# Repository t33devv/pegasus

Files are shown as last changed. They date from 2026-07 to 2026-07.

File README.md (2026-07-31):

# Pegasus
Quadruped Robot Dog

Fusion360 CAD


Pegasus has 4 legs, each a parallel five-bar linkage driven by two servos, plus a roll servo per leg (12 servos total). Controlled by a **Pimoroni Servo 2040** (RP2040) running **Pimoroni's MicroPython** connected to **Visual Studio Code** on a laptop.

This GitHub repo is the official repo for the open source project Pegasus.

This is a guide on the contents of this repo:

| # | Path | Contents |
|---|---|---|
| 1 | **`pegasus/PARTS_LIST.csv`** | contains the link, name, and price of all the materials you need for this build. |
| 2 | **`pegasus/CAD/`** | only has .stp files, which you can directly print. The only 2 files that aren't .stp files is `ExportedPartQuantities.csv` (which tells you the quantity of each part to print) and `README.md`. |
| 3 | **`pegasus/CODE/`** | only has files that contain code. It has a balance of INO (Arduino) and PY (Python) files. Read more at `pegasus/CODE/README.md` about that specific folder. |

---

If you have any questions about Pegasus, make sure to join my [**Discord Community**](https://discord.gg/ShXfuxmhje) :p

Made with ❤️ by Tobias (and Harrison Milburn!)

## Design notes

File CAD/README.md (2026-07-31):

[Harrison Milburn](https://www.youtube.com/@HarrisonMilburnYT) is the original owner of the CAD files, and has graciously let me Open Source them.

Make sure to go check his [YouTube channel](https://www.youtube.com/@HarrisonMilburnYT) and [Patreon](https://www.patreon.com/cw/HarrisonMilburn)!

Also, a lot of the 3D prints require supports. Make sure to turn that on in your 3D Printing slicing software.

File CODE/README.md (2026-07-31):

# CODE

This directory contains all firmware and laptop-side software for Pegasus.

All `*.py` files in `CODE/` run **on the Pimoroni Servo 2040 board** via MicroPython. Files in `TELEOP/` that run on the laptop are noted explicitly below. For full hardware reference (wiring, torso calibration values, IK geometry, serial protocol, safety rules), see `ROBOT_DOG.md`.

---

## Uploading firmware to the board

1. Open VS Code with the **MicroPico** extension installed and connected to the Servo 2040.
2. Right-click the file in the Explorer → **"Upload file to Pico"**, or use `Cmd+Shift+P` → **"MicroPico: Upload current file to Pico"**.
3. `main.py` autoruns on power-up — any other filename must be triggered manually via the MicroPico REPL.

> **Before running any file:** ensure the board has USB-C connected (logic power) and the 6V bench supply is on (servo power). See `ROBOT_DOG.md` for full wiring details and safety rules.

---

## Files in `CODE/`

| File | What it does | How to run |
|---|---|---|
| `4_servo_test.py` | Tests 4 servos on headers 1–4 — confirms wiring and pulse calibration. | Upload to board, run via MicroPico REPL. |
| `4_legs_test.py` | Raw 8-servo leg test (no IK) — wiggles each motor in sequence to confirm pairing and direction. | Upload to board, run via MicroPico REPL. |
| `imu_read.py` | Reads MPU6050 accel + gyro at 5 Hz — use this to verify axis directions and sensor wiring. | Upload to board, run via MicroPico REPL. USB power only (servo rail not needed). |
| `tof_read.py` | Reads VL53L0X distance sensor in mm — use this to verify ToF wiring. Requires `vl53l0x.py` on the board. | Upload to board, run via MicroPico REPL. USB power only. |
| `torso_calibration.py` | Interactive helper — type an angle at the prompt to move one torso servo until the leg hangs vertical. Set `WHICH` to the torso index before uploading. | Upload to board, run via MicroPico REPL. |
| `torso_test.py` | Torso-only test — seeds all torsos at flat, ramps to stand, dips halfway, then lies back down. | Upload to board, run via MicroPico REPL. |
| `torso_twist.py` | Rocks the dog side-to-side by combining torso lean and leg depth changes over `ROCK_COUNT` cycles. | Upload to board, run via MicroPico REPL. |
| `crawl_gait.py` | Diagonal-pair alternating trot for a fixed number of cycles (`GAIT_CYCLES`). | Upload to board, run via MicroPico REPL. |
| `tripedal_balance.py` | Raises each leg in sequence, pre-shifting the CG over the support triangle first. | Upload to board, run via MicroPico REPL. |
| `all_dog_test.py` | Full demo sequence: stand, walk forward, torso twist, tripedal balance, walk backward, twist, lie down. | Upload to board, run via MicroPico REPL. |
| `balance.py` | Active roll + pitch stabilisation using the MPU6050 — continuous 20 ms control loop. Keep the dog still for the first ~2 s of gyro calibration. | Upload to board, run via MicroPico REPL. |
| `vl53l0x.py` | VL53L0X MicroPython driver — must be uploaded to the board alongside any file that uses the ToF sensor. | Upload to board (no need to run directly). |
| `sketch_jul22a.ino` | **Obsolete** Arduino/PCA9685 original — reference only, not used in the current build. | — |

---

## TELEOP system (`TELEOP/`)

The teleop system lets you drive Pegasus in real time from a laptop — via a keyboard/web UI or by voice.

### Step 1 — Upload the firmware

```bash
cp TELEOP/teleop_dog.py TELEOP/main.py
```

Upload `TELEOP/main.py` to the board (right-click → "Upload file to Pico"). `main.py` autoruns on power-up.

### Step 2 — Disconnect MicroPico

Click the MicroPico icon in the VS Code status bar, or `Cmd+Shift+P` → **"MicroPico: Disconnect"**. This releases the serial port so the laptop scripts can connect.

> Do **not** use "Run current file" for teleop — MicroPico holds the serial port open while running.

### Step 3 — Reset the board

Press the reset button on the Servo 2040 (or power-cycle it). The board will stand up, calibrate the IMU (~2 s, keep the dog still), then print `ready` and wait for commands.

### Option A — Web UI (keyboard control)

```bash
cd TELEOP
pip install websockets pyserial          # one-time
python bridge.py                         # auto-detects serial port
```

Open `http://localhost:8080` in a browser. Hold **W / A / S / D** to drive, release to stop. **Space** stops. **E** toggles Walk / Run mode.

```bash
# If auto-detect fails, pass the port manually:
python bridge.py --port /dev/tty.usbmodemXXXX   # macOS
python bridge.py --port COM3                      # Windows
```

### Option B — Voice control

**One-time setup:**

```bash
cd TELEOP
pip install faster-whisper pyserial sounddevice soundfile numpy python-dotenv

# Download the Whisper model (~150 MB, cached to ~/.cache/huggingface/):
python -c "from faster_whisper import WhisperModel; WhisperModel('base', device='cpu', compute_type='int8')"
```

**Running:**

```bash
cd TELEOP
source .venv/bin/activate
python voice_control.py                  # auto-detects serial port
```

Press **Enter** to start recording, **Enter** again to stop. Spoken commands include:

| Say | What happens |
|-----|---|
| "forward", "go ahead" | Walk forward |
| "backward", "reverse" | Walk backward |
| "left" / "right" | Spin continuously |
| "turn left 90 degrees" | IMU-guided 90° left turn |
| "walk forward 3 meters" | Walk forward ~3 m (open-loop), then stop |
| "stop", "halt", "freeze" | Stop |
| "stand up", "get up" | Ramp torsos to stand |
| "lay down", "lie down" | Ramp torsos to flat |
| "jump" / "leap" | Jump motion |
| "fast feet", "quick feet" | Rapid sequential foot lifts |
| "lift front right foot" | Lift foot 1 and hold 2 s |

Compound commands work too: `"turn left 90 degrees and walk forward 3 meters"`.

```bash
# Optional: calibrate open-loop speed/turn constants
python voice_control.py --calibrate-speed
python voice_control.py --calibrate-turn
```

---

## Debugging utilities

| File | Purpose | How to run |
|---|---|---|
| `TELEOP/diagnose_imu.py` | Sends an IMU turn command and prints all board serial output — use to verify gz signs and turn accuracy. | `python3 TELEOP/diagnose_imu.py L 90` (laptop, board must be running `main.py`). |
| `TELEOP/test_stt.py` | Records audio, prints peak/RMS level, runs through Whisper — use to verify mic input before robot testing. | `python3 TELEOP/test_stt.py` (laptop, inside `.venv`). |

---

## TELEOP file reference

| File | What it is |
|---|---|
| `TELEOP/teleop_dog.py` | Firmware source — edit this file. |
| `TELEOP/main.py` | Exact copy of `teleop_dog.py` — always sync with `cp teleop_dog.py main.py`, then upload this to the board. |
| `TELEOP/bridge.py` | Laptop-side bridge: serves the web UI on port 8080 and forwards commands over serial. |
| `TELEOP/index.html` | Web gamepad UI served by `bridge.py`. |
| `TELEOP/voice_control.py` | Laptop-side voice controller: mic → Whisper STT → command parser → serial. |
| `TELEOP/.env` | Stores `OPENAI_API_KEY` (kept for future use; current STT is fully offline). |
| `TELEOP/.venv/` | Python virtual environment with all laptop-side dependencies. |

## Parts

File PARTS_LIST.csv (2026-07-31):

 | BILL OF MATERIALS:
Required? | Item Name | Price ($ USD) | Quantity | Link
YES | 6004ZZ Bearings (10pcs) | 14.69 | 2 | https://www.amazon.com/dp/B071GLNRW6?ref=ppx_yo2ov_dt_b_fed_asin_title
YES | Metal Servo Horn (20pcs) | 16.99 | 1 | https://www.amazon.com/dp/B0CMX7S3K5?ref=ppx_yo2ov_dt_b_fed_asin_title&th=1
YES | Servo Motor (6pcs) | 21.39 | 2 | https://www.amazon.com/KEAcvise-Packs-mg996r-servo-Motor/dp/B0FGP9ZPJN?sp_csd=d2lkZ2V0TmFtZT1zcF9hdGY
YES | Pimoroni Servo 2040 | 20.94 (£15.6) | 1 | https://shop.pimoroni.com/products/servo-2040?variant=39800591679571
YES | Screws (M2 - M5)
YES | Thin Nuts (M2 - M5)
NO | MPU-6050 | 8.99 | 1 | https://www.amazon.com/EPLZON-MPU-6050-Accelerometer-Gyroscope-Converter/dp/B09TVYVC6X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
NO | VL53L0X (3pcs) | 12.99 | 1 | https://www.amazon.com/Qoroos-VL53L0X-Breakout-Interface-Communication/dp/B0F1MRW55R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
 |  |  |  |  | TOTAL PRICE
 |  |  |  |  | 119.08
 | SUPPLIES:
Required? | Item Name
YES | Minimum 5V 5A Power Supply
YES | 3D Printer
YES | Screwdriver
YES | Jumper wires
YES | ~18AWG power wires
YES | Breadboard
NO | Gopro (or any camera)
NO | Long USBC cables
NO | Alligator clips

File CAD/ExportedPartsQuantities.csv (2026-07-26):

Part Number | Quantity
HM02-08-007 | 1
HM02-08-006 | 2
HM02-07-011 | 4
HM02-07-010 | 4
HM02-07-009 | 4
HM02-07-008 | 4
HM02-07-007 | 8
Amazon - B07F71J1Q2 | 16
6004ZZ ill | 16
HM02-07-006 | 4
HM02-07-005 | 4
Amazon - B09V5B6SB6 | 12
HM02-07-004 | 4
HM02-07-003 | 4
HM02-07-002 | 4
HM02-07-001 | 4
HM02-08-003 | 1
HM02-08-001 | 4
HM02-08-002 | 2

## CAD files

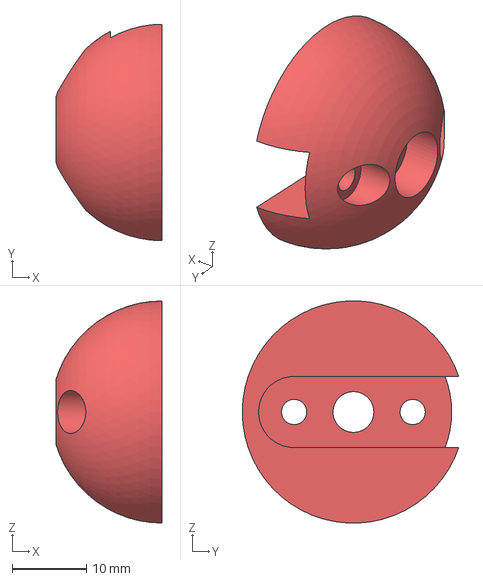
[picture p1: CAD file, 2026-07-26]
CAD/HM02-07-010 UNCONTROLLED.stp
14.4 x 29.2 x 30.0 mm

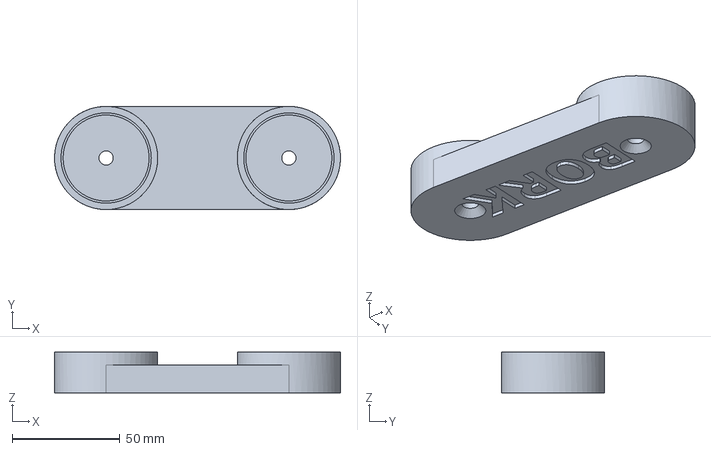
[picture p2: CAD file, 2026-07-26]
CAD/HM02-08-006 UNCONTROLLED.stp
133.0 x 48.0 x 19.0 mm

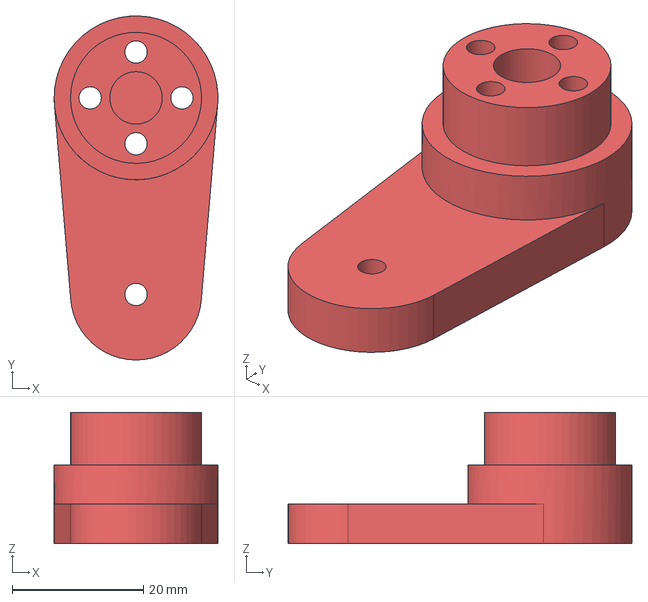
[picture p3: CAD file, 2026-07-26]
CAD/HM02-07-007 UNCONTROLLED.stp
25.0 x 52.5 x 20.0 mm

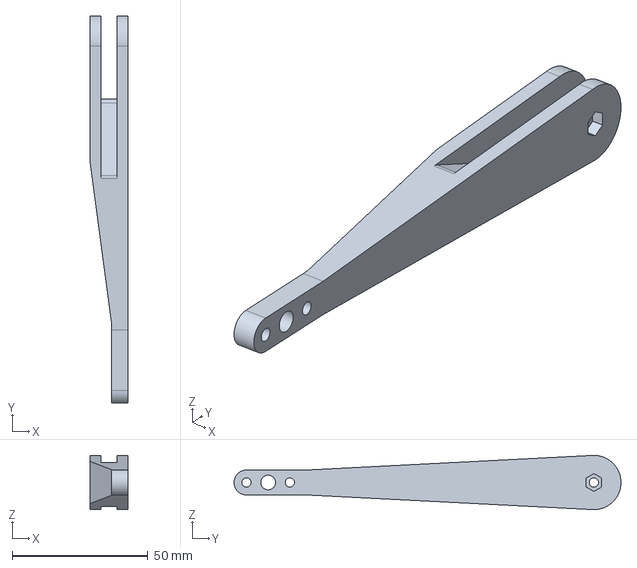
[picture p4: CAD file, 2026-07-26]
CAD/HM02-07-009 UNCONTROLLED.stp
14.0 x 142.6 x 20.0 mm

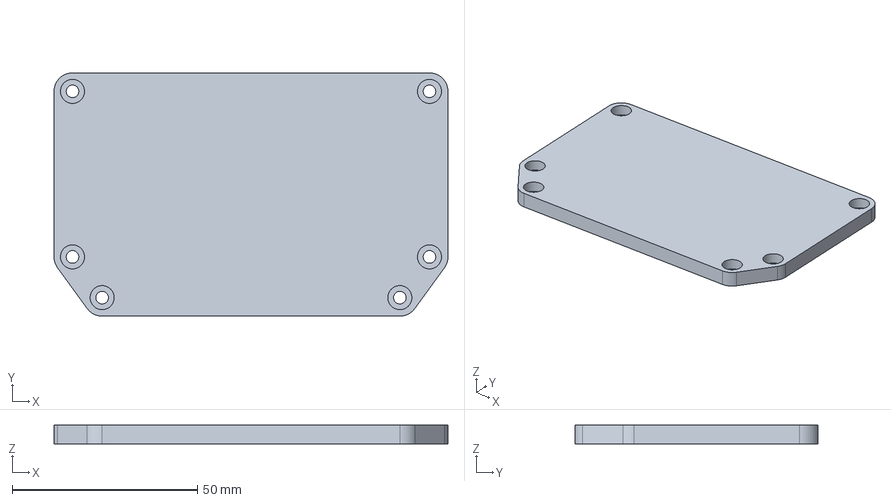
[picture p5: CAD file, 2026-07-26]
CAD/HM02-07-004 UNCONTROLLED.stp
106.4 x 65.7 x 5.00 mm

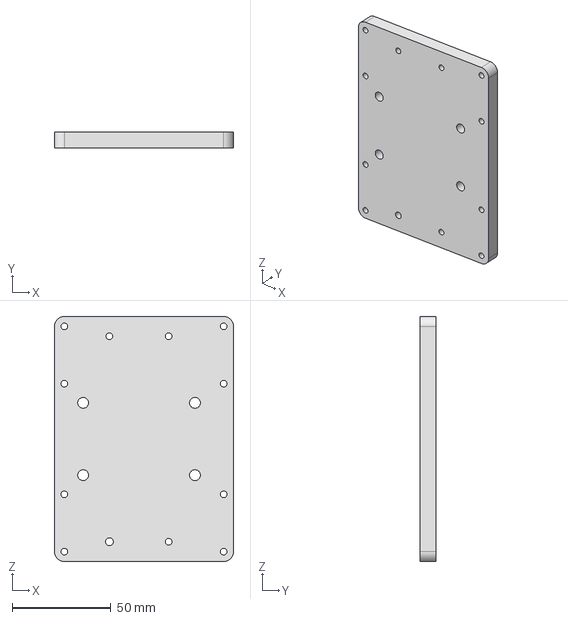
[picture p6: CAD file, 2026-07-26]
CAD/HM02-08-003 UNCONTROLLED.step
90.6 x 8.00 x 124.0 mm

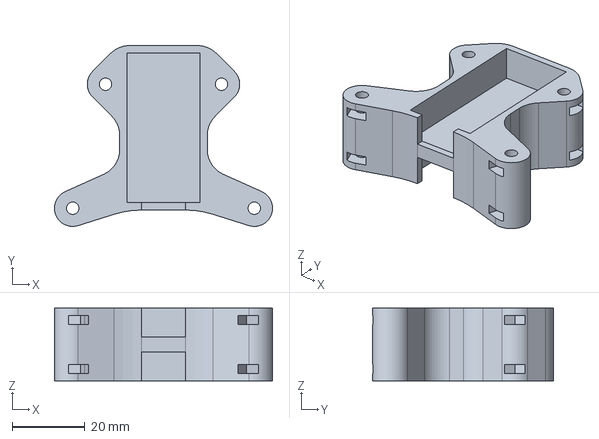
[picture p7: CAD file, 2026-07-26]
CAD/HM02-08-002 UNCONTROLLED.stp
59.8 x 49.6 x 20.0 mm

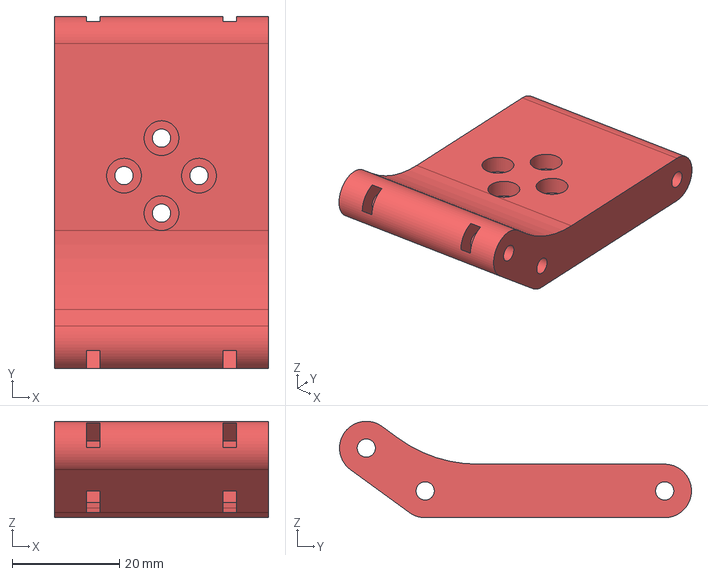
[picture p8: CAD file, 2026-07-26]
CAD/HM02-07-002 UNCONTROLLED.stp
40.0 x 65.7 x 18.0 mm

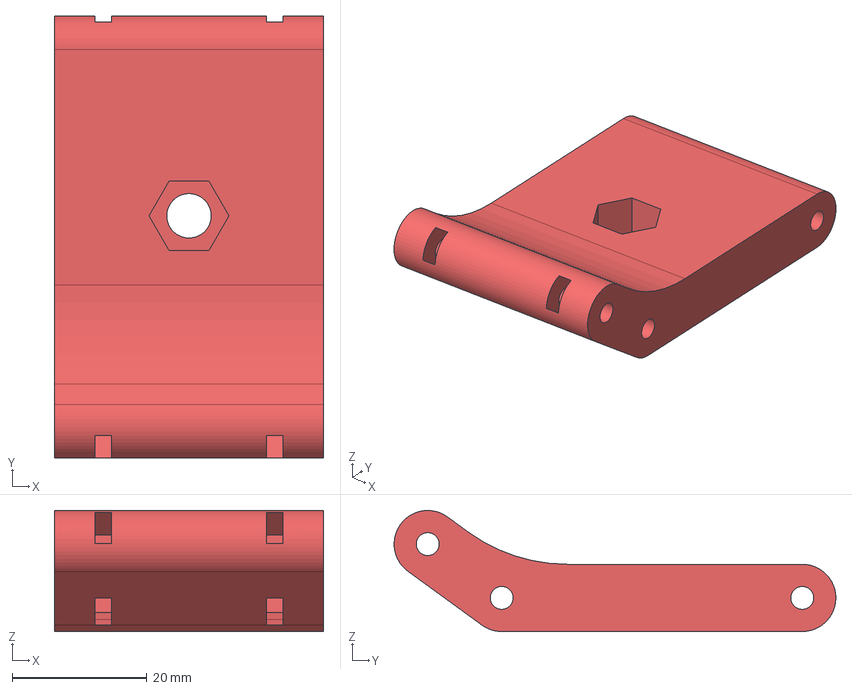
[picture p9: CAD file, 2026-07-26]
CAD/HM02-07-003 UNCONTROLLED.stp
40.0 x 65.7 x 18.0 mm

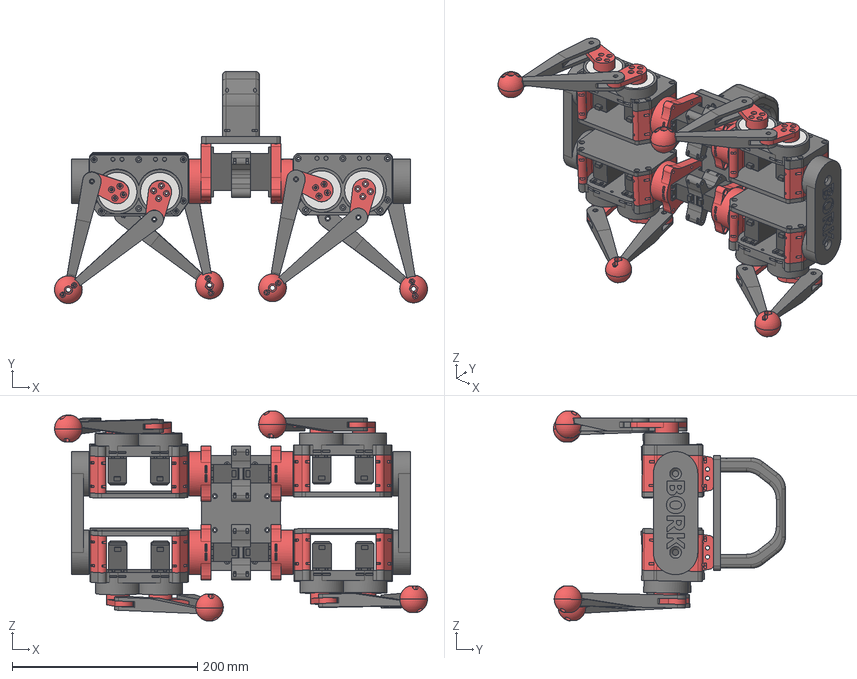
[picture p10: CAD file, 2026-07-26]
CAD/HM-02-08-005.stp
403.0 x 250.7 x 226.5 mm
HM02-08-001 x 4
HM02-08-002 x 2
Amazon - B09V5B6SB6 x 12
Amazon - B07F71J1Q2 x 12
HM02-08-003
HM02-07-001 x 4
HM02-07-002 x 4
HM02-07-003 x 4
HM02-07-004 x 4
6004ZZ ill x 16
HM02-07-005 x 4
HM02-07-006 x 4
HM02-07-007 x 8
HM02-07-008 x 4
HM02-07-009 x 4
HM02-07-010 x 4
HM02-07-011 x 4
HM02-08-006 x 2
HM02-08-007

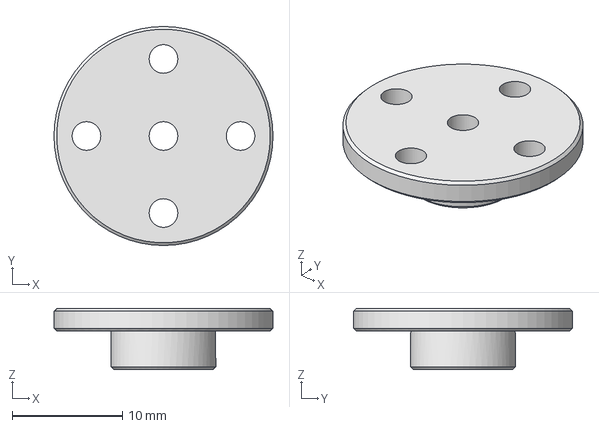
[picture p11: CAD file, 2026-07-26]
CAD/Amazon - B07F71J1Q2 UNCONTROLLED.stp
19.9 x 19.9 x 5.56 mm

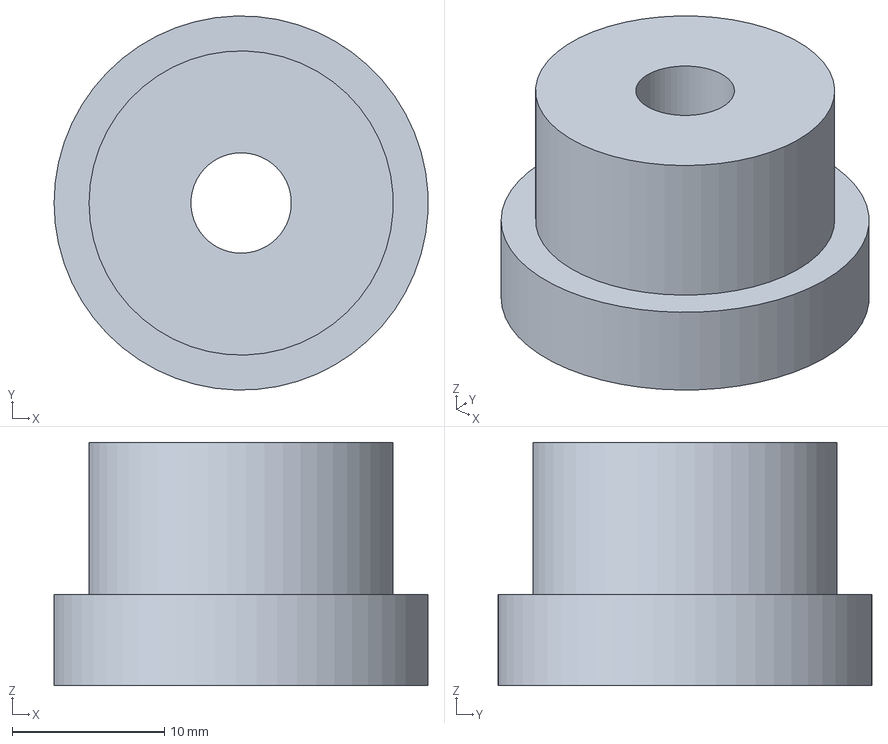
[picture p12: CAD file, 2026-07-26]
CAD/HM02-07-005 UNCONTROLLED.step
24.6 x 24.6 x 16.0 mm

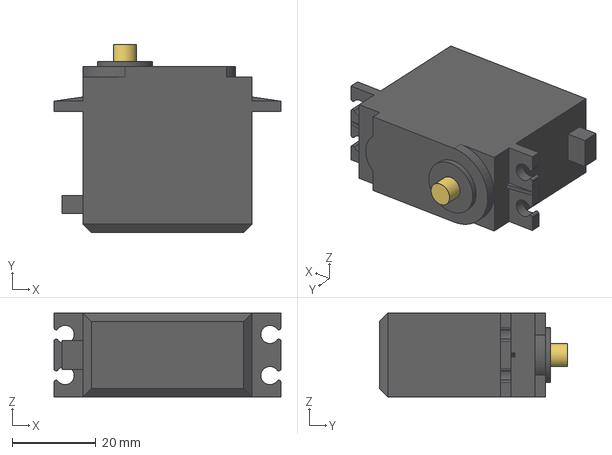
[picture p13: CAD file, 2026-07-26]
CAD/Amazon - B09V5B6SB6 UNCONTROLLED.stp
54.1 x 44.8 x 20.0 mm

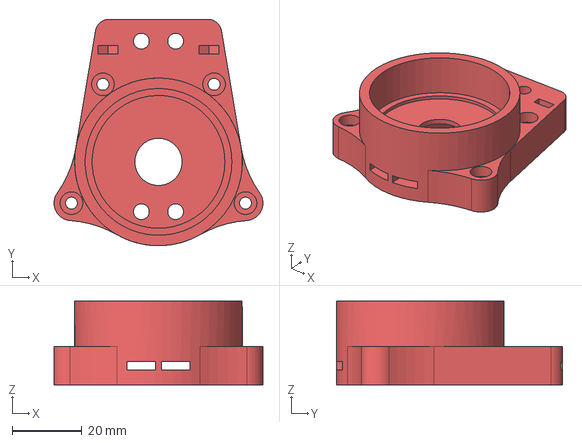
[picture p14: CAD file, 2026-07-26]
CAD/HM02-08-001 UNCONTROLLED.stp
59.8 x 64.8 x 24.0 mm

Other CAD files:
CAD/HM02-07-011 UNCONTROLLED.stp
CAD/HM02-07-008 UNCONTROLLED.stp
CAD/HM02-07-001 UNCONTROLLED.stp
CAD/6004ZZ ill UNCONTROLLED.stp
CAD/HM02-07-006 UNCONTROLLED.step
CAD/HM02-08-007 UNCONTROLLED.stp
CAD/m5_to_m6_nut_adapter.step

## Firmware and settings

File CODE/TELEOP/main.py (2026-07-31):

# teleop_dog.py — Pimoroni Servo 2040 (MicroPython)
#
# Listens for commands over USB serial and drives the gait:
#   f = walk forward    b = walk backward
#   l = turn left       r = turn right  (continuous, until 's')
#   s / Space = stop (hold stand)
#   L<N>\n = IMU-guided left turn N degrees   e.g. "L90\n"
#   R<N>\n = IMU-guided right turn N degrees  e.g. "R45\n"
#
# Workflow (MicroPico in VS Code):
#   1. Cmd+Shift+P → "MicroPico: Upload current file to Pico"
#      — OR right-click this file in Explorer → "Upload file to Pico"
#      Then rename it main.py on the board so it autoruns on power-up.
#   2. Disconnect MicroPico: click the MicroPico icon in the VS Code status bar,
#      or Cmd+Shift+P → "MicroPico: Disconnect". This releases the serial port.
#   3. Reset/power-cycle the board — teleop_dog.py starts automatically.
#   4. Run bridge.py on the laptop.
#
# Do NOT use "Run current file" for teleop — MicroPico keeps the serial port
# open while running, so bridge.py cannot connect.
#
# Ctrl-C stops the loop and disables servos.

import time
import math
import select
import sys
from machine import I2C, Pin
from servo import ServoCluster, Calibration, servo2040

# ---- hardware ----
cal = Calibration()
cal.apply_two_pairs(610, 2441, -90, 90)
pins = list(range(servo2040.SERVO_1, servo2040.SERVO_12 + 1))
cluster = ServoCluster(0, 0, pins, cal)

# ---- geometry ----
L1 = 30.0;  L2 = 120.0;  HS = 46.0
LEG_MIN = 20.0;  LEG_MAX = 160.0

# ---- gait parameters ----
STANCE_Y    = 132.0
LIFT        =  18.0
STRIDE      =  40.0
STANCE_DUTY =   0.6
CYCLE_MS    = 1200
TICK_MS     =  20

# ---- run parameters (faster gait) ----
RUN_CYCLE_MS = 700
RUN_STRIDE   = 55.0
RUN_LIFT     = 24.0

# ---- torso calibration ----
TORSO_CAL = [
    ( 9,  8,  60.0, 160.0),
    (10,  9, 110.0,  10.0),
    (11, 10, 110.0,   5.0),
    (12, 11,  70.0, 170.0),
]
TORSO_LIMITS = {
    idx: (min(stand, flat), max(stand, flat))
    for _, idx, stand, flat in TORSO_CAL
}

# ---- ToF obstacle avoidance ----
TOF_ENABLED  = False  # set True to block forward motion when obstacle detected
OBSTACLE_MM  = 100   # block forward motion below this distance (10 cm)
TOF_INTERVAL =   5   # read sensor every N ticks (5 × 20ms = 100ms)

# ---- IMU (MPU6050) for precise angle turns ----
MPU_ADDR       = 0x68
_GYRO_XOUT     = 0x43   # start of 6-byte gyro block (same as balance.py)
_GYRO_SCALE    = 131.0  # LSB per °/s at ±250°/s default range
_IMU_CAL_N     = 100    # calibration samples (~2 s) — matches balance.py
# Moving-average window to smooth gait vibration before integrating.
_GZ_SMOOTH_N   = 5
# Sign of gz for each turn direction — confirmed from diagnose_imu output:
# R turns produce negative gz_raw; L turns produce positive gz_raw.
# If one direction consistently over/underturns, flip its sign here.
GZ_SIGN        = {'L': 1, 'R': -1}
# Minimum signed gz to accumulate — filters standstill noise.
GZ_MIN_DPS     = 3.0
# Abort if the turn hasn't finished within this multiple of the estimated time.
GYRO_TIMEOUT_FACTOR = 4

def _find_i2c(target_addr):
    """Return an I2C bus object that has target_addr on it, or None."""
    combos = []
    try:
        combos.append((0, servo2040.SDA, servo2040.SCL))
        combos.append((1, servo2040.SDA, servo2040.SCL))
    except Exception:
        pass
    for bus in (0, 1):
        for sda, scl in ((4, 5), (20, 21), (0, 1)):
            combos.append((bus, sda, scl))
    for bus, sda, scl in combos:
        try:
            i2c = I2C(bus, sda=Pin(sda), scl=Pin(scl))
            found = i2c.scan()
            if len(found) > 20: continue   # stuck/shorted bus
            if target_addr in found:
                return i2c
        except Exception:
            pass
    return None

def setup_tof():
    """Return (tof_object, read_method_name) or (None, None) if unavailable."""
    i2c = _find_i2c(0x29)
    if i2c is None:
        print("ToF: not found — obstacle avoidance disabled")
        return None, None
    try:
        import vl53l0x
        tof = vl53l0x.VL53L0X(i2c)
    except ImportError:
        try:
            from VL53L0X import VL53L0X
            tof = VL53L0X(i2c)
        except Exception as e:
            print("ToF: driver missing —", e)
            return None, None
    start = getattr(tof, "start", None)
    if start: start()
    for name in ("read", "read_range", "ping"):
        if getattr(tof, name, None):
            print("ToF: ready —", name)
            return tof, name
    if hasattr(tof, "range"):
        return tof, "range"
    print("ToF: unknown driver interface")
    return None, None

def tof_read_mm(tof_obj, method):
    try:
        return tof_obj.range if method == "range" else getattr(tof_obj, method)()
    except Exception:
        return 9999   # treat read error as clear path


def _imu_read_gyro(i2c):
    """Read all 6 gyro bytes in one I2C transaction — same pattern as balance.py.
    Returns (gx_raw, gy_raw, gz_raw) as signed integers (LSB, not yet scaled)."""
    g = i2c.readfrom_mem(MPU_ADDR, _GYRO_XOUT, 6)
    def s16(hi, lo):
        v = (hi << 8) | lo
        return v - 65536 if v > 32767 else v
    return s16(g[0], g[1]), s16(g[2], g[3]), s16(g[4], g[5])

def setup_imu():
    """Find MPU6050, wake it, calibrate gz offset. Returns (i2c, gz_offset_raw) or (None, 0).
    gz_offset_raw is in raw LSB — subtracted before dividing by _GYRO_SCALE.
    Keep Pegasus still during the calibration window."""
    i2c = _find_i2c(MPU_ADDR)
    if i2c is None:
        print("IMU: not found — angle turns fall back to open-loop timing")
        return None, 0
    i2c.writeto_mem(MPU_ADDR, 0x6B, b'\x00')   # wake up (clear sleep bit)
    time.sleep_ms(500)   # let the board settle after standing up
    print("IMU: calibrating gz ({} samples, keep still)...".format(_IMU_CAL_N))
    gz_sum = 0
    for _ in range(_IMU_CAL_N):
        _, _, gz_raw = _imu_read_gyro(i2c)
        gz_sum += gz_raw
        time.sleep_ms(20)
    gz_offset_raw = gz_sum // _IMU_CAL_N   # integer raw LSB offset
    print("IMU: ready, gz_offset_raw={}".format(gz_offset_raw))
    return i2c, gz_offset_raw


# ---- modes ----
STOP      = 0
WALK_FWD  = 1
WALK_BACK = 2
TURN_L    = 3
TURN_R    = 4
RUN_FWD   = 5
RUN_BACK  = 6

CMD_MAP = {
    ord('f'): WALK_FWD,
    ord('b'): WALK_BACK,
    ord('F'): RUN_FWD,
    ord('B'): RUN_BACK,
    ord('l'): TURN_R,
    ord('r'): TURN_L,
    ord('s'): STOP,
    ord(' '): STOP,
}


# ---- IK ----

def legIK(fx, fy):
    dxL = fx - HS / 2;  dxR = fx + HS / 2
    DL  = math.sqrt(dxL * dxL + fy * fy)
    DR  = math.sqrt(dxR * dxR + fy * fy)
    if not (abs(L2 - L1) < DL < L1 + L2): return None
    if not (abs(L2 - L1) < DR < L1 + L2): return None
    cosL = max(-1.0, min(1.0, (L1*L1 + DL*DL - L2*L2) / (2*L1*DL)))
    cosR = max(-1.0, min(1.0, (L1*L1 + DR*DR - L2*L2) / (2*L1*DR)))
    phi_L = math.atan2( dxL, fy) + math.acos(cosL)
    phi_R = math.atan2(-dxR, fy) + math.acos(cosR)
    return 135.0 - math.degrees(phi_L), math.degrees(phi_R) + 45.0


# ---- servo helpers ----

def leg_set(idx, angle, load=True):
    cluster.value(idx, max(LEG_MIN, min(LEG_MAX, float(angle))) - 90.0, load)

def torso_raw(idx, angle, load=True):
    lo, hi = TORSO_LIMITS[idx]
    cluster.value(idx, max(lo, min(hi, float(angle))) - 90.0, load)

def torso_ramp(from_frac, to_frac, ms):
    t0 = time.ticks_ms()
    while True:
        el = time.ticks_diff(time.ticks_ms(), t0)
        if el >= ms: break
        f = from_frac + (to_frac - from_frac) * (el / ms)
        for _, idx, stand, flat in TORSO_CAL:
            torso_raw(idx, flat + (stand - flat) * f, False)
        cluster.load()
        time.sleep_ms(TICK_MS)
    for _, idx, stand, flat in TORSO_CAL:
        torso_raw(idx, flat + (stand - flat) * to_frac, False)
    cluster.load()

def set_home(home):
    for li, ri in ((0, 1), (2, 3), (4, 5), (6, 7)):
        leg_set(li, home[0], False)
        leg_set(ri, home[1], False)
    cluster.load()


# ---- gait helpers ----

def _ease(t):
    return t * t * (3.0 - 2.0 * t)

def foot_pos(phase, direction=1, stride=STRIDE, lift=LIFT):
    sw = 1.0 - STANCE_DUTY
    if phase < sw:
        t = phase / sw
        x = direction * (-stride + 2.0 * stride * _ease(t))
        y = STANCE_Y - lift * math.sin(math.pi * t)
    else:
        t = (phase - sw) / STANCE_DUTY
        x = direction * (stride - 2.0 * stride * t)
        y = STANCE_Y
    return x, y

def apply_leg(li, ri, phase, fwd=1, direction=1, stride=STRIDE, lift=LIFT):
    fx, fy = foot_pos(phase, direction, stride, lift)
    ik = legIK(fx * fwd, fy)
    if ik is None: return
    leg_set(li, ik[0], False)
    leg_set(ri, ik[1], False)


# ---- serial command read (non-blocking) ----
# Single-byte commands (f/b/l/r/s) are returned as ord() integers as before.
# Angle commands L<N>\n / R<N>\n are accumulated over multiple ticks and
# returned as ('imu_turn', 'L'|'R', degrees_float) when \n is received.

_cmd_buf = []

def read_cmd():
    global _cmd_buf
    r, _, _ = select.select([sys.stdin], [], [], 0)
    if not r:
        return None
    b = sys.stdin.read(1)
    if not b:
        return None
    ch = b   # MicroPython sys.stdin.read(1) returns a str

    # Accumulating a buffered angle command
    if _cmd_buf:
        if ch.isdigit():
            _cmd_buf.append(ch)
            return None
        elif ch == '\n':
            direction = _cmd_buf[0]
            try:
                degrees = float(''.join(_cmd_buf[1:]))
            except Exception:
                degrees = 0.0
            _cmd_buf = []
            return ('imu_turn', direction, degrees) if degrees > 0 else None
        else:
            _cmd_buf = []   # unexpected char — abandon and fall through

    # Start of a buffered angle command
    if ch in ('L', 'R'):
        _cmd_buf = [ch]
        return None

    # Single-byte commands (unchanged)
    return ord(ch)


# ---- IMU-guided turn ----

def imu_guided_turn(direction, target_deg, home, imu_i2c, gz_offset_raw):
    """
    Turn by target_deg degrees using gyro integration to know when to stop.
    direction: 'L' (left) or 'R' (right).

    Reads gyro the same way as balance.py — all 6 bytes in one I2C burst from
    0x43, subtracts the raw-integer offset calibrated at startup, then applies
    a _GZ_SMOOTH_N-tick moving average to reduce gait vibration before integrating.
    """
    if imu_i2c is None or target_deg <= 0:
        return

    # TURN_R physically turns left because CMD_MAP already swapped the labels.
    gait_mode = TURN_R if direction == 'L' else TURN_L

    gz_buf      = [0] * _GZ_SMOOTH_N   # raw-LSB ring buffer for smoothing
    buf_idx     = 0
    accumulated = 0.0
    t_prev      = time.ticks_ms()
    t0          = t_prev
    timeout_ms  = int(target_deg / 22.5 * 1000 * GYRO_TIMEOUT_FACTOR)
    print("IMU turn: {}{:.0f}deg".format(direction, target_deg))

    while accumulated < target_deg:
        _, _, gz_raw = _imu_read_gyro(imu_i2c)
        gz_buf[buf_idx] = gz_raw - gz_offset_raw
        buf_idx = (buf_idx + 1) % _GZ_SMOOTH_N

        # Signed: positive = rotating in the commanded direction.
        # Gait vibration spikes in the wrong direction subtract from the
        # buffer average rather than adding (unlike abs which counts both).
        gz_dps = GZ_SIGN[direction] * (sum(gz_buf) / _GZ_SMOOTH_N) / _GYRO_SCALE

        t_now = time.ticks_ms()
        dt    = time.ticks_diff(t_now, t_prev) / 1000.0
        t_prev = t_now
        if gz_dps > GZ_MIN_DPS:
            accumulated += gz_dps * dt

        if time.ticks_diff(t_now, t0) > timeout_ms:
            print("IMU turn: timeout after {:.1f}deg".format(accumulated))
            break

        # One gait tick — mirrors the main loop turn logic exactly
        el = time.ticks_diff(t_now, t0)
        p  = (el % CYCLE_MS) / CYCLE_MS
        pB = (p + 0.5) % 1.0

        if gait_mode == TURN_L:
            apply_leg(0, 1, p,  fwd=-1, direction=-1)
            apply_leg(6, 7, p,  fwd= 1, direction= 1)
            apply_leg(2, 3, pB, fwd= 1, direction= 1)
            apply_leg(4, 5, pB, fwd=-1, direction=-1)
        else:
            apply_leg(0, 1, p,  fwd=-1, direction= 1)
            apply_leg(6, 7, p,  fwd= 1, direction=-1)
            apply_leg(2, 3, pB, fwd= 1, direction=-1)
            apply_leg(4, 5, pB, fwd=-1, direction= 1)

        cluster.load()
        time.sleep_ms(TICK_MS)

    set_home(home)
    print("IMU turn done: {:.1f}deg".format(accumulated))


# ---- one-shot action commands ----

_torso_frac = 0.0   # tracked so stand/lay always ramp from the current position

# Foot index → (left_servo, right_servo) pairs.
# Order: 0=front-right, 1=front-left, 2=back-right, 3=back-left.
# NOTE: left/right is assumed — swap pairs if the wrong foot lifts.
_FOOT_LEGS = [(0, 1), (2, 3), (4, 5), (6, 7)]

def cmd_stand_up(home):
    global _torso_frac
    torso_ramp(_torso_frac, 1.0, 1500)
    _torso_frac = 1.0
    set_home(home)
    print("standing")

def cmd_lay_down():
    global _torso_frac
    torso_ramp(_torso_frac, 0.0, 1500)
    _torso_frac = 0.0
    print("lying down")

def cmd_jump(home):
    # Smooth large-range dip-and-rise: sink body low then lift it high.
    # IK is valid for fy ∈ (87, 148) with fx=0 given L1=30, L2=120, HS=46.
    LOW_Y  = 146.0   # body sunk low  (legs extended toward ground)
    HIGH_Y =  93.0   # body lifted high (legs retracted)
    for y_from, y_to, ms in (
        (STANCE_Y, LOW_Y,   700),   # sink
        (LOW_Y,    HIGH_Y, 900),    # rise
        (HIGH_Y,   STANCE_Y, 600),  # return
    ):
        t0 = time.ticks_ms()
        while True:
            el = time.ticks_diff(time.ticks_ms(), t0)
            if el >= ms:
                break
            y  = y_from + (y_to - y_from) * (el / ms)
            ik = legIK(0.0, y)
            if ik:
                for li, ri in ((0,1),(2,3),(4,5),(6,7)):
                    leg_set(li, ik[0], False)
                    leg_set(ri, ik[1], False)
                cluster.load()
            time.sleep_ms(TICK_MS)
        ik = legIK(0.0, y_to)
        if ik:
            for li, ri in ((0,1),(2,3),(4,5),(6,7)):
                leg_set(li, ik[0], False)
                leg_set(ri, ik[1], False)
            cluster.load()
    set_home(home)
    print("jumped")

def cmd_fast_feet(home, cycles=4):
    # Lift each foot in sequence very quickly — like "fast feet" running drill
    up = legIK(0.0, STANCE_Y - 20.0)
    if up is None:
        return
    for _ in range(cycles):
        for li, ri in _FOOT_LEGS:
            leg_set(li, up[0], False)
            leg_set(ri, up[1], False)
            cluster.load()
            time.sleep_ms(60)
            leg_set(li, home[0], False)
            leg_set(ri, home[1], False)
            cluster.load()
            time.sleep_ms(60)
    print("fast feet done")

def cmd_lift_foot(foot_idx, home):
    up = legIK(0.0, STANCE_Y - 28.0)
    if up is None:
        return
    set_home(home)
    li, ri = _FOOT_LEGS[foot_idx]
    leg_set(li, up[0], False)
    leg_set(ri, up[1], False)
    cluster.load()
    print("lifted foot {}".format(foot_idx + 1))
    time.sleep_ms(2000)
    set_home(home)


# ---- main ----

def main():
    for _, idx, _, flat in TORSO_CAL:
        torso_raw(idx, flat, False)
    home = legIK(0.0, STANCE_Y)
    if home is None:
        print("ERROR: home position unreachable — check L1/L2/HS")
        return
    set_home(home)
    cluster.load()
    cluster.enable_all()
    time.sleep_ms(500)

    print("standing up...")
    torso_ramp(0.0, 1.0, 2500)
    global _torso_frac
    _torso_frac = 1.0   # track torso position so stand/lay ramp from correct state

    tof_obj, tof_method = setup_tof() if TOF_ENABLED else (None, None)
    imu_i2c, gz_offset_raw = setup_imu()
    last_dist_mm = 9999
    tof_counter  = 0

    print("ready — f/b/l/r/s  |  L<deg>\\n / R<deg>\\n  |  U/D/J/T/1-4 one-shot actions")

    # One-shot action byte map: U=stand_up D=lay_down J=jump T=fast_feet 1-4=lift_foot
    ONE_SHOT = {
        ord('U'): ('stand_up',),
        ord('D'): ('lay_down',),
        ord('J'): ('jump',),
        ord('T'): ('fast_feet',),
        ord('1'): ('lift_foot', 0),
        ord('2'): ('lift_foot', 1),
        ord('3'): ('lift_foot', 2),
        ord('4'): ('lift_foot', 3),
    }

    mode = STOP
    t0   = time.ticks_ms()

    while True:
        cmd = read_cmd()
        if cmd is not None:
            if isinstance(cmd, tuple):
                # IMU-guided angle turn — blocking until target reached
                _, direction, degrees = cmd
                imu_guided_turn(direction, degrees, home, imu_i2c, gz_offset_raw)
                mode = STOP
                t0 = time.ticks_ms()
            elif cmd in ONE_SHOT:
                act = ONE_SHOT[cmd]
                if act[0] == 'stand_up':
                    cmd_stand_up(home)
                elif act[0] == 'lay_down':
                    cmd_lay_down()
                elif act[0] == 'jump':
                    cmd_jump(home)
                elif act[0] == 'fast_feet':
                    cmd_fast_feet(home)
                elif act[0] == 'lift_foot':
                    cmd_lift_foot(act[1], home)
                mode = STOP
                t0 = time.ticks_ms()
            else:
                new_mode = CMD_MAP.get(cmd, mode)
                if new_mode != mode:
                    mode = new_mode
                    if mode == STOP:
                        set_home(home)

        # poll ToF every TOF_INTERVAL ticks
        if TOF_ENABLED:
            tof_counter += 1
            if tof_counter >= TOF_INTERVAL:
                tof_counter = 0
                if tof_obj is not None:
                    last_dist_mm = tof_read_mm(tof_obj, tof_method)

        obstacle = TOF_ENABLED and (last_dist_mm < OBSTACLE_MM)

        if mode != STOP:
            if mode in (RUN_FWD, RUN_BACK):
                cycle = RUN_CYCLE_MS; s = RUN_STRIDE; lft = RUN_LIFT
            else:
                cycle = CYCLE_MS;    s = STRIDE;     lft = LIFT
            el = time.ticks_diff(time.ticks_ms(), t0)
            p  = (el % cycle) / cycle
            pB = (p + 0.5) % 1.0

            if mode in (WALK_FWD, RUN_FWD) and not obstacle:
                apply_leg(0, 1, p,  fwd=-1, direction= 1, stride=s, lift=lft)
                apply_leg(6, 7, p,  fwd= 1, direction= 1, stride=s, lift=lft)
                apply_leg(2, 3, pB, fwd= 1, direction= 1, stride=s, lift=lft)
                apply_leg(4, 5, pB, fwd=-1, direction= 1, stride=s, lift=lft)
            elif mode in (WALK_BACK, RUN_BACK):
                apply_leg(0, 1, p,  fwd=-1, direction=-1, stride=s, lift=lft)
                apply_leg(6, 7, p,  fwd= 1, direction=-1, stride=s, lift=lft)
                apply_leg(2, 3, pB, fwd= 1, direction=-1, stride=s, lift=lft)
                apply_leg(4, 5, pB, fwd=-1, direction=-1, stride=s, lift=lft)
            elif mode == TURN_L:
                # right side (fwd=1 legs) forward, left side (fwd=-1 legs) backward
                # if it spins the wrong way, swap TURN_L and TURN_R in CMD_MAP
                apply_leg(0, 1, p,  fwd=-1, direction=-1)
                apply_leg(6, 7, p,  fwd= 1, direction= 1)
                apply_leg(2, 3, pB, fwd= 1, direction= 1)
                apply_leg(4, 5, pB, fwd=-1, direction=-1)
            elif mode == TURN_R:
                apply_leg(0, 1, p,  fwd=-1, direction= 1)
                apply_leg(6, 7, p,  fwd= 1, direction=-1)
                apply_leg(2, 3, pB, fwd= 1, direction=-1)
                apply_leg(4, 5, pB, fwd=-1, direction= 1)

            cluster.load()

        time.sleep_ms(TICK_MS)


try:
    main()
except KeyboardInterrupt:
    pass
finally:
    cluster.disable_all()
    print("servos disabled")

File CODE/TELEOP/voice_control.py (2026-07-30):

#!/usr/bin/env python3
"""
voice_control.py — Voice command interface for Pegasus (quadruped robot dog).

Pegasus accepts single ASCII bytes over USB serial at 115200 baud:
    f = walk forward    b = walk backward
    l = turn left       r = turn right
    s = stop

Timed moves (e.g. "forward 3 metres") send the motion byte, wait the
computed duration, then send 's'. Distance and angle conversions are
open-loop and approximate — calibrate METERS_PER_SECOND / DEGREES_PER_SECOND
before trusting them. Use --calibrate-speed and --calibrate-turn.

pip install faster-whisper pyserial sounddevice soundfile numpy python-dotenv

One-time model download (run once, then works offline):
    python -c "from faster_whisper import WhisperModel; WhisperModel('base', device='cpu', compute_type='int8')"
Model is cached in ~/.cache/huggingface/ (~150 MB). Delete that folder to re-download.

Usage:
    python voice_control.py                        # voice control loop
    python voice_control.py --port /dev/tty.usbmodem1101
    python voice_control.py --calibrate-speed      # measure forward speed
    python voice_control.py --calibrate-turn       # measure turn rate
"""

import os
import re
import sys
import time
import tempfile
import threading
from pathlib import Path
from typing import Optional

import numpy as np

# Load TELEOP/.env (or any parent .env) so you can store keys there instead of
# setting them in the shell. python-dotenv is optional — falls back gracefully.
try:
    from dotenv import load_dotenv
    load_dotenv(Path(__file__).parent / ".env")
except ImportError:
    pass

# ─────────────────────────────────────────────────────────────
# TUNABLE CONSTANTS — set these before your first run
# ─────────────────────────────────────────────────────────────

# Serial port connecting to the Servo 2040.
# None = auto-detect the first RP2040/MicroPython USB device found.
# Override example: SERIAL_PORT = "/dev/tty.usbmodem1101"
SERIAL_PORT = None
BAUD_RATE   = 115200

# Open-loop speed estimates — these are rough defaults. Run --calibrate-speed
# and --calibrate-turn to measure real values, then paste them here.
METERS_PER_SECOND  = 0.15   # approximate forward walk speed (m/s)
DEGREES_PER_SECOND = 22.5   # approximate spin rate (°/s)

# Recording
SAMPLE_RATE        = 16000  # Hz — Whisper works well at 16 kHz
MAX_RECORD_SECONDS = 10     # hard cap: stream is stopped after this many seconds


# ─────────────────────────────────────────────────────────────
# SERIAL HELPERS
# ─────────────────────────────────────────────────────────────

def find_serial_port() -> Optional[str]:
    try:
        import serial.tools.list_ports
    except ImportError:
        return None
    for p in serial.tools.list_ports.comports():
        dev  = p.device.lower()
        desc = (p.description or "").lower()
        if "usbmodem" in dev or "micropython" in desc or "rp2040" in desc or "pico" in desc:
            return p.device
    # Fallback: first available port
    ports = list(serial.tools.list_ports.comports())
    return ports[0].device if ports else None


def open_serial(port: Optional[str] = None, baud: int = BAUD_RATE):
    import serial
    port = port or find_serial_port()
    if not port:
        sys.exit(
            "[serial] ERROR: could not find Pegasus's serial port.\n"
            "Pass --port /dev/tty.usbmodemXXXX or set SERIAL_PORT at the top of this file."
        )
    ser = serial.Serial(port, baud, timeout=1)
    print(f"[serial] Connected: {port} @ {baud} baud")
    return ser


def send_command(ser, byte: str) -> None:
    """Send a single ASCII byte to Pegasus and log it."""
    ser.write(byte.encode())
    print(f"[serial] Sent: {repr(byte)}")


# ─────────────────────────────────────────────────────────────
# AUDIO RECORDING
# ─────────────────────────────────────────────────────────────

def record_audio() -> str:
    """
    Push-to-key recording: press Enter to start, Enter again to stop.
    Returns the path to a temporary WAV file.
    """
    import sounddevice as sd
    import soundfile as sf

    print("\n[mic] Press Enter to START recording...")
    input()

    frames = []

    def _callback(indata, _frames, _time, _status):
        frames.append(indata.copy())

    # The 'with' block starts the stream; second input() waits for stop.
    # A daemon thread enforces the hard cap so a missed Enter can't hang forever.
    stop_event = threading.Event()

    def _timeout_guard():
        stop_event.wait(MAX_RECORD_SECONDS)

    threading.Thread(target=_timeout_guard, daemon=True).start()

    with sd.InputStream(samplerate=SAMPLE_RATE, channels=1,
                        dtype="float32", callback=_callback):
        print(f"[mic] Recording... Press Enter to STOP (max {MAX_RECORD_SECONDS}s).")

        def _wait_enter():
            input()
            stop_event.set()

        t = threading.Thread(target=_wait_enter, daemon=True)
        t.start()
        stop_event.wait()           # block until Enter pressed or timeout

    if not frames:
        raise RuntimeError("[mic] No audio captured — check your microphone.")

    audio = np.concatenate(frames, axis=0)
    duration = len(audio) / SAMPLE_RATE
    print(f"[mic] Captured {duration:.1f}s of audio.")

    tmp = tempfile.NamedTemporaryFile(suffix=".wav", delete=False)
    sf.write(tmp.name, audio, SAMPLE_RATE)
    return tmp.name


# ─────────────────────────────────────────────────────────────
# SPEECH-TO-TEXT
# Swap this function body to change the STT backend (e.g. Vosk, Faster-Whisper).
# Contract: receives a WAV path, returns a plain-text string.
# ─────────────────────────────────────────────────────────────

def _load_whisper_model():
    """Load faster-whisper once and cache it for the session.
    Device priority: CUDA GPU → Apple Silicon (MPS, via cpu+int8 which is
    still fast on M-series) → CPU. faster-whisper doesn't expose MPS directly
    but int8 on Apple Silicon is already ~10× faster than real-time."""
    from faster_whisper import WhisperModel
    try:
        import torch
        if torch.cuda.is_available():
            device, compute_type = "cuda", "float16"
            print("[stt]    Device: CUDA GPU")
        elif torch.backends.mps.is_available():
            # faster-whisper's CTranslate2 backend doesn't use Metal directly;
            # fall back to CPU int8 which is highly optimised on Apple Silicon.
            device, compute_type = "cpu", "int8"
            print("[stt]    Device: Apple Silicon CPU (int8 — optimised for M-series)")
        else:
            device, compute_type = "cpu", "int8"
            print("[stt]    Device: CPU (int8)")
    except ImportError:
        device, compute_type = "cpu", "int8"
        print("[stt]    Device: CPU (int8)")
    return WhisperModel("base", device=device, compute_type=compute_type)

_whisper_model = None   # loaded on first call, reused for every subsequent call
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

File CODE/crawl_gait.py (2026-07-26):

# Crawl gait — Pimoroni Servo 2040 (MicroPython)
#
# Diagonal-pair alternating gait (trot-style crawl):
#   Pair A — legs 1 & 4 (headers 1-2 and 7-8, idx 0-1 / 6-7): swing together
#   Pair B — legs 2 & 3 (headers 3-4 and 5-6, idx 2-3 / 4-5): 180° offset
# One pair swings (foot lifts and steps forward) while the other pushes in stance.
# Torsos ramp to stand before the gait, return to flat after.
#
# If a leg pair walks backwards instead of forwards, negate the x coordinate
# for that pair in the apply_leg() calls at the bottom of main().
#
# Channel map (header → index → role):
#   1→0 leg1 L   2→1 leg1 R   3→2 leg2 L   4→3 leg2 R
#   5→4 leg3 L   6→5 leg3 R   7→6 leg4 L   8→7 leg4 R
#   9→8 torso1  10→9 torso2  11→10 torso3  12→11 torso4

import time
import math
from servo import ServoCluster, Calibration, servo2040

# ---- hardware ----
cal = Calibration()
cal.apply_two_pairs(610, 2441, -90, 90)
pins = list(range(servo2040.SERVO_1, servo2040.SERVO_12 + 1))
cluster = ServoCluster(0, 0, pins, cal)

# ---- IK geometry ----
L1 = 30.0    # upper link length (mm)
L2 = 120.0   # lower link length (mm)
HS = 46.0    # centre-to-centre of the two pulley axes (mm)

# ---- leg servo limits ----
LEG_MIN = 20.0
LEG_MAX = 160.0

# ---- gait tuning ----
STANCE_Y    = 132.0   # foot depth in stance (mm, +y = down)
LIFT        =  18.0   # swing arc peak height above stance (mm)
STRIDE      =  40.0   # half-stride; foot sweeps -STRIDE..+STRIDE in x (mm)
STANCE_DUTY =   0.6   # fraction of cycle spent in stance (swing = 1 - this)
CYCLE_MS    = 1200    # duration of one full step cycle (ms)
GAIT_CYCLES =   8     # how many cycles to run before stopping

# ---- torso calibration (hand-measured, both ends) ----
# (header, cluster_index, stand_angle, flat_angle)
TORSO_CAL = [
    ( 9,  8,  60.0, 160.0),
    (10,  9, 110.0,  10.0),
    (11, 10, 110.0,   5.0),
    (12, 11,  70.0, 170.0),
]
TORSO_LIMITS = {
    idx: (min(stand, flat), max(stand, flat))
    for _, idx, stand, flat in TORSO_CAL
}


# ---- five-bar IK ----

def legIK(fx, fy):
    """
    Compute (servoL, servoR) in 0-180° for a foot at (fx, fy).
    Coordinate frame: +x toward left/forward motor side, +y downward.
    Origin is the midpoint between the two pulley axes.
    Returns None if the foot is outside the reachable workspace.
    Neutral (0, 132.77) → (90, 90). Stance depth 138 is well within range.
    """
    # Vector from each hip to the foot
    dxL =  fx - HS / 2    # left hip at (+HS/2, 0)
    dxR =  fx + HS / 2    # right hip at (-HS/2, 0)
    DL  = math.sqrt(dxL * dxL + fy * fy)
    DR  = math.sqrt(dxR * dxR + fy * fy)

    reach_min = abs(L2 - L1)   # 90 mm
    reach_max = L1 + L2        # 150 mm
    if not (reach_min < DL < reach_max): return None
    if not (reach_min < DR < reach_max): return None

    cosL = max(-1.0, min(1.0, (L1*L1 + DL*DL - L2*L2) / (2*L1*DL)))
    cosR = max(-1.0, min(1.0, (L1*L1 + DR*DR - L2*L2) / (2*L1*DR)))

    # +acos branch → knees splayed outward (matches the build)
    # Right side uses negated x so both arms measure angle symmetrically from vertical
    phi_L = math.atan2( dxL, fy) + math.acos(cosL)
    phi_R = math.atan2(-dxR, fy) + math.acos(cosR)

    sL = 135.0 - math.degrees(phi_L)
    sR = math.degrees(phi_R) + 45.0
    return sL, sR


# ---- helpers ----

def leg_set(idx, angle, load=True):
    cluster.value(idx, max(LEG_MIN, min(LEG_MAX, float(angle))) - 90.0, load)


def torso_raw(idx, angle, load=True):
    lo, hi = TORSO_LIMITS[idx]
    cluster.value(idx, max(lo, min(hi, float(angle))) - 90.0, load)


def torso_ramp(from_frac, to_frac, ms):
    """Smoothly move all torsos between two flat→stand fractions."""
    t0 = time.ticks_ms()
    while True:
        el = time.ticks_diff(time.ticks_ms(), t0)
        if el >= ms:
            break
        f = from_frac + (to_frac - from_frac) * (el / ms)
        for _, idx, stand, flat in TORSO_CAL:
            torso_raw(idx, flat + (stand - flat) * f, False)
        cluster.load()
        time.sleep_ms(20)
    for _, idx, stand, flat in TORSO_CAL:
        torso_raw(idx, flat + (stand - flat) * to_frac, False)
    cluster.load()


# ---- gait trajectory ----

def _ease(t):
    # smoothstep: zero velocity at both endpoints, cuts the servo-rate spike
    return t * t * (3.0 - 2.0 * t)

def foot_pos(phase):
    """
    Returns (x, y) foot position for normalised phase in [0, 1).
    Swing (first 40%): eased x so the foot accelerates out of stance and
    decelerates into touchdown — eliminates the velocity spike at transitions.
    Stance (last 60%): constant-depth push, linear x sweep.
    """
    sw = 1.0 - STANCE_DUTY                                  # swing duty = 0.4
    if phase < sw:
        t  = phase / sw                                     # 0..1 within swing
        ex = _ease(t)
        x  = -STRIDE + 2.0 * STRIDE * ex                   # eased rear → front
        y  = STANCE_Y - LIFT * math.sin(math.pi * t)       # sine lift arc
    else:
        t = (phase - sw) / STANCE_DUTY                     # 0..1 within stance
        x = STRIDE - 2.0 * STRIDE * t                      # linear front → rear
        y = STANCE_Y
    return x, y
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

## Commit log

2026-07-25 micropython code for pimoroni servo2040
2026-07-26 update dog name
    [6004ZZ ill UNCONTROLLED.stp, Amazon - B07F71J1Q2 UNCONTROLLED.stp, Amazon - B09V5B6SB6 UNCONTROLLED.stp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]
2026-07-29 added IMU and ToF
2026-07-30 rename Sona → Pegasus; add voice control, IMU turns, one-shot commands
    - Rename robot from Sona to Pegasus throughout
    - Add voice_control.py: faster-whisper STT, serial command dispatch, compound
    commands via "and"/"then" splitting
    - Add IMU-guided turns (MPU6050 gyro integration, signed gz, moving average)
    - Add one-shot commands: stand up (U), lay down (D), jump (J), fast feet (T),
    lift foot 1-4
    - Add ToF obstacle avoidance, diagnose_imu.py debug tool, test_stt.py
    - Smooth large-range jump motion (dip → rise ramp over IK range)
    [diagnose_imu.py, main.py, teleop_dog.py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]
2026-07-31 add parts list
    [PARTS_LIST.csv]
